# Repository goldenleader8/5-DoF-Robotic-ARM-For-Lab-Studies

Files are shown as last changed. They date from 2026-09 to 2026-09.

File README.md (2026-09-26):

# 5-DoF Robotic ARM For Lab Studies

Purwarupa lengan robot 5-Derajat Kebebasan (5-DoF) yang dikembangkan oleh **Kelompok Studi Robotika (KSR)**, Fakultas Teknologi Industri, Universitas Atma Jaya Yogyakarta (UAJY), sebagai instrumen pembelajaran dan praktikum untuk mata kuliah **Otomasi Industri dan Robotika**.

Proyek ini menjembatani teori kinematika ruang tiga dimensi dengan penerapan nyata pada perangkat keras fisik, melalui tiga tahap utama: **pemodelan**, **pembuatan purwarupa**, dan **pengujian pergerakan sendi**.

## Fitur Utama

- **Forward Kinematics (FK)** — melacak posisi koordinat ujung lengan (end-effector) secara presisi berdasarkan input sudut sendi, menggunakan parameter Denavit-Hartenberg (DH) hybrid yang diekstraksi langsung dari desain URDF.
- **Inverse Kinematics (IK)** — diselesaikan dengan algoritma analitik-numerik **Damped Least Squares (DLS)** untuk menstabilkan pergerakan di area singularitas mekanis, tanpa memerlukan pelatihan AI.
- **Simulasi Virtual (MATLAB)** — lingkungan simulasi berbasis URDF sebagai lapisan perlindungan sebelum program dieksekusi ke mesin fisik, termasuk simulasi Monte Carlo (30.000 kombinasi sudut sendi acak) untuk memetakan titik rawan tabrakan.
- **Interlock Keamanan** — sistem kendali Python memblokir eksekusi trajektori yang berpotensi menabrak bidang kerja (meja).

## Struktur Perangkat Keras

- Base link, tiga tautan ekstensi menengah, dan end-effector — dicetak 3D menggunakan filamen PETG pada printer Creality Ender 3 V3 Plus.
- Desain komponen dibuat menggunakan Autodesk Fusion.
- Lima motor servo **Dynamixel AX-12A** yang dirangkai seri, menyediakan engsel putar independen untuk base, bahu, siku, dan pergelangan tangan ganda.
- Kendali menggunakan mikrokontroler dengan komunikasi serial pada 57600 bps.

## Struktur Repositori

```
├── 5DofARM.py              # Skrip kendali utama (FK, IK/DLS, komunikasi serial ke Dynamixel)
├── Simulasi_URDF_GUI.m     # GUI simulasi lengan robot berbasis URDF di MATLAB
├── Test_Collision.m        # Simulasi Monte Carlo untuk deteksi area rawan tabrakan
├── LICENSE
└── README.md
```

## Dasar Matematika

### Forward Kinematics — Transformasi Homogen Denavit-Hartenberg

Setiap frame *i* dihubungkan ke frame sebelumnya melalui matriks transformasi homogen 4x4:

```
        [ cosθᵢ   -sinθᵢ·cosαᵢ    sinθᵢ·sinαᵢ    aᵢ·cosθᵢ ]
Tᵢ  =   [ sinθᵢ    cosθᵢ·cosαᵢ   -cosθᵢ·sinαᵢ    aᵢ·sinθᵢ ]
        [   0         sinαᵢ          cosαᵢ          dᵢ    ]
        [   0            0              0            1    ]
```

Keterangan:
- `Tᵢ` : matriks transformasi homogen
- `θᵢ` : sudut sendi (joint angle)
- `αᵢ` : pilin link (link twist)
- `aᵢ` : panjang link (link length)
- `dᵢ` : offset link (link offset)

Posisi akhir end-effector diperoleh dari perkalian berurutan seluruh matriks transformasi frame (8 frame, kombinasi sendi dinamis dan frame statis hasil ekstraksi geometri fisik robot).

**Parameter DH robot ini:**

| Frame (i) | aᵢ (m) | αᵢ (°) | dᵢ (m) | θᵢ (°) | Keterangan |
|---|---|---|---|---|---|
| 1 | 0.0 | 0.0 | 0.021 | θ₁* | Base joint dinamis (Yaw) |
| 2 | 0.0075 | -90.0 | 0.006448 | 90.0 | Transisi orientasi sumbu bahu |
| 3 | 0.036878 | 0.0 | 0.0215 | θ₂* | Shoulder joint dinamis (Pitch) |
| 4 | 0.120266 | 0.0 | -0.0051 | 16.3429 | Geometri statis Link 1 |
| 5 | 0.036878 | 0.0 | 0.005 | θ₃* | Elbow joint dinamis (Pitch) |
| 6 | 0.008 | 90.0 | 0.015 | 102.529 | Geometri statis Link 2 |
| 7 | 0.036878 | 0.0 | 0.0735 | θ₄* | Wrist joint dinamis (Pitch) |
| 8 | 0.008 | 90.0 | 0.0465 | 102.529 | Jarak absolut ke End-Effector |

\* `θₓ*` merepresentasikan variabel sudut dinamis dari aktuator, yang berubah real-time sesuai hasil perhitungan inverse kinematics.

### Inverse Kinematics — Damped Least Squares (DLS)

Untuk menghindari ketidakstabilan pada titik singularitas mekanis (kelemahan metode pseudo-invers konvensional), perubahan sudut sendi per iterasi dihitung dengan menambahkan faktor redaman:

```
Δθₖ = Jᵀ (J·Jᵀ + λ²·I)⁻¹ · eₖ
```

Keterangan:
- `Δθₖ` : vektor perubahan sudut sendi
- `J` : matriks Jacobian numerik (dihitung dengan diferensiasi maju berhingga)
- `Jᵀ` : transpos matriks Jacobian
- `λ` : skalar redaman (damping factor)
- `I` : matriks identitas
- `eₖ` : vektor error spasial (spatial error)

Iterasi berlangsung hingga vektor error spasial konvergen menuju target koordinat, tanpa mekanisme *joint limit clamping* (dinonaktifkan untuk menghindari minima lokal).

## Hasil Eksperimen (Ringkasan)

| Aspek | Hasil |
|---|---|
| Deviasi rata-rata Forward Kinematics | 0,0555 m (X: 0,0315 m, Y: 0,0358 m, Z: 0,0153 m) |
| Error residual Inverse Kinematics (DLS) | 1–4 mm (0,25%–1,02% dari radius jangkauan) |
| Batas keamanan vertikal bawah | 0,025 m |

## Persyaratan

- Python 3.x dengan pustaka `dynamixel_sdk`
- MATLAB (untuk simulasi URDF dan uji tabrakan)
- Port serial (COM) untuk komunikasi dengan motor Dynamixel AX-12A

## Cara Menjalankan

1. Hubungkan motor Dynamixel AX-12A ke port serial (default: `COM6`, baudrate `57600`).
2. Jalankan `5DofARM.py` untuk mengendalikan lengan robot secara langsung.
3. Gunakan `Simulasi_URDF_GUI.m` di MATLAB untuk menjalankan simulasi virtual sebelum eksekusi ke perangkat fisik.
4. Gunakan `Test_Collision.m` untuk menjalankan simulasi Monte Carlo dan memvalidasi batas ruang kerja aman.

## Kontributor

Kelompok Studi Robotika (KSR), Fakultas Teknologi Industri, Universitas Atma Jaya Yogyakarta.

- **Desain & perakitan hardware (lengan robot, 3D printing, wiring)**: [Dionisio Raditya](https://github.com/dionisioraditya) 
- **Software (FK/IK, kontrol Python, simulasi MATLAB/URDF)**: Jonathan.

## Lisensi

Proyek ini dilisensikan di bawah [MIT License](LICENSE).

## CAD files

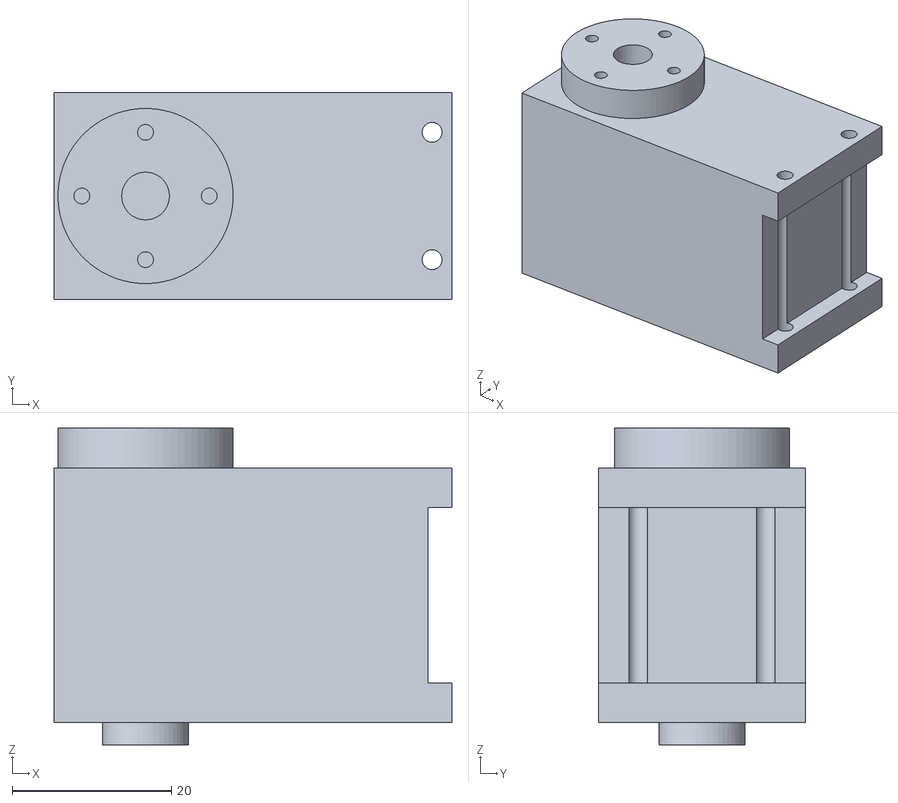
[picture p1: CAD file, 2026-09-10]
meshes/AX_12A_remake-v1-2.stl
50.0 x 26.0 x 39.8

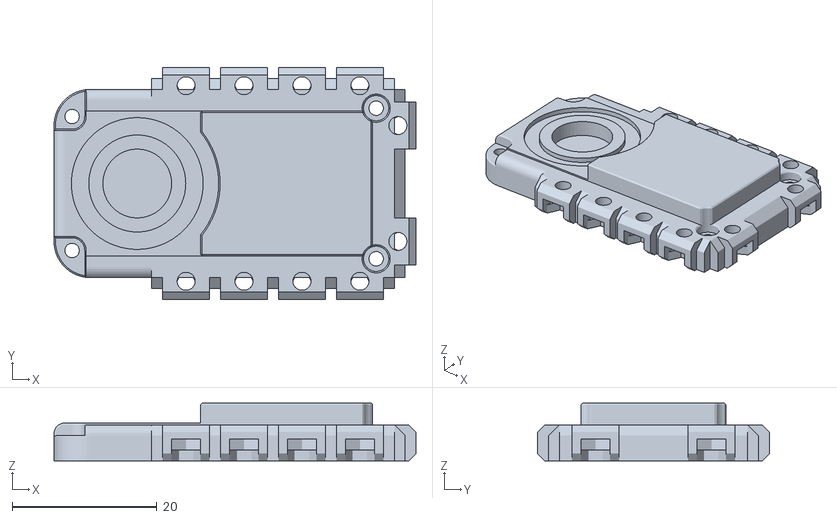
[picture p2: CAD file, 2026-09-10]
meshes/holder-v2_AX-12A-v1-7_AX-12A-02-7.stl
50.0 x 32.0 x 8.00

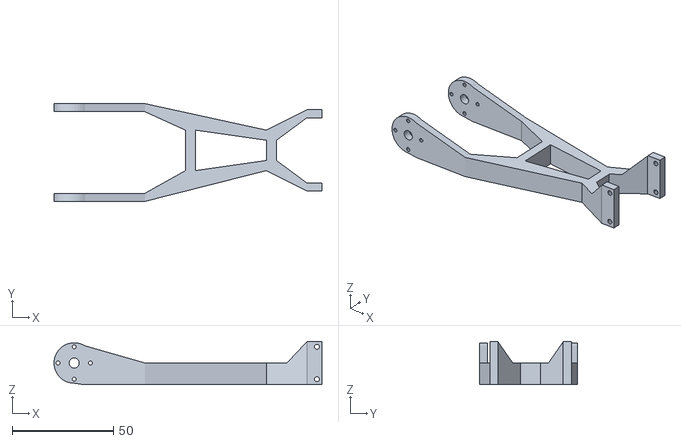
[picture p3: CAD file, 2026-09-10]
meshes/link_1_v2-v6.stl
132.5 x 48.3 x 21.5

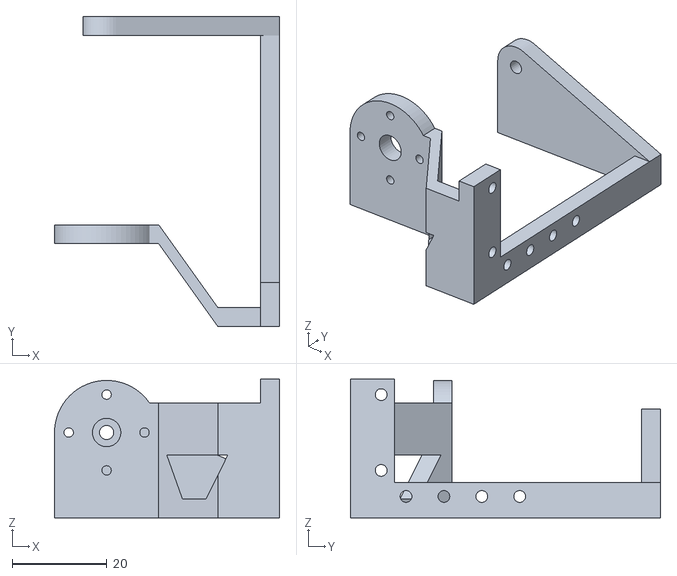
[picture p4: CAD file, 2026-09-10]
meshes/link_2_V2-v5.stl
47.5 x 65.5 x 29.2

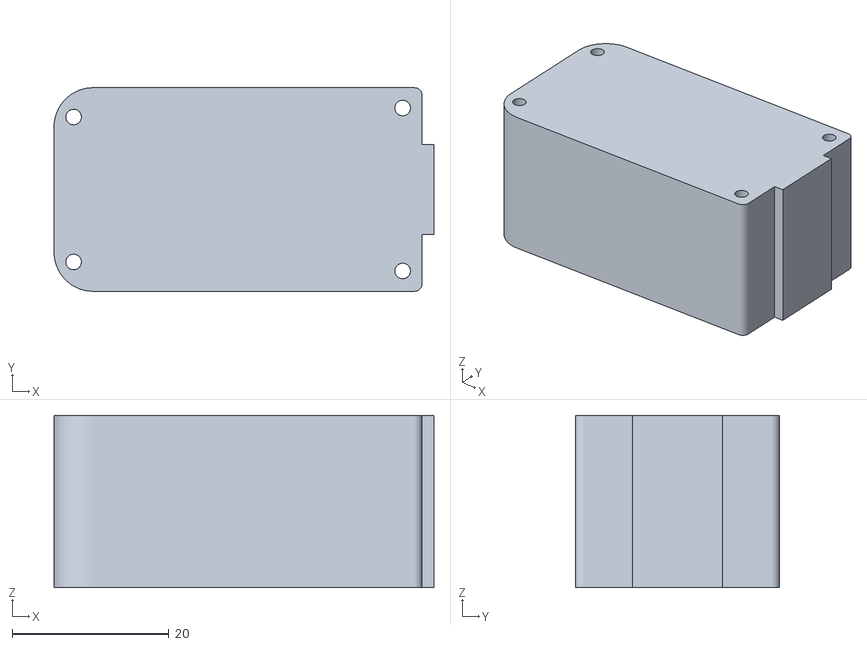
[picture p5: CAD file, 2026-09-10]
meshes/holder-v2_AX-12A-v1-7_AX-12A-01-7.stl
48.5 x 26.0 x 22.0

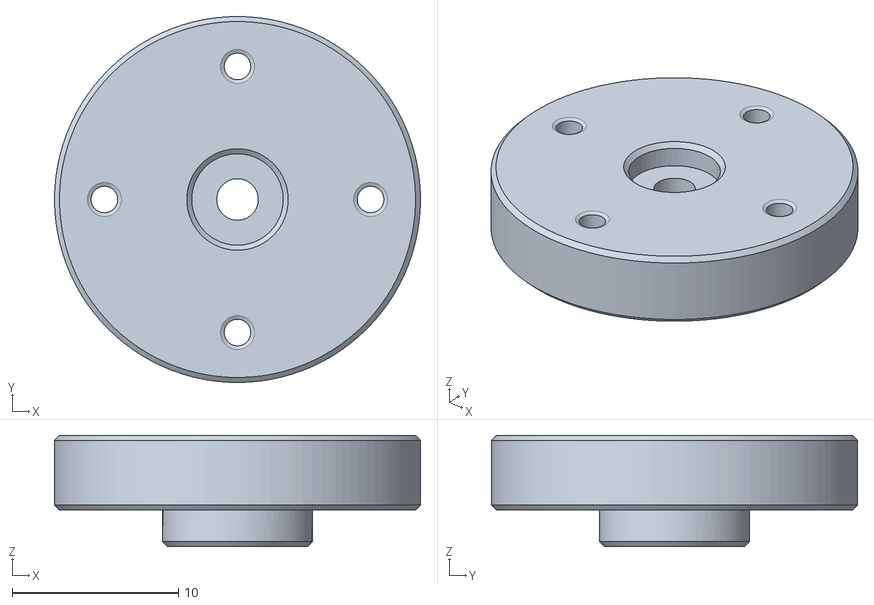
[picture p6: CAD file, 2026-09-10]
meshes/holder-v2_AX-12A-v1-7_AX-12A-04-7.stl
22.0 x 22.0 x 6.70

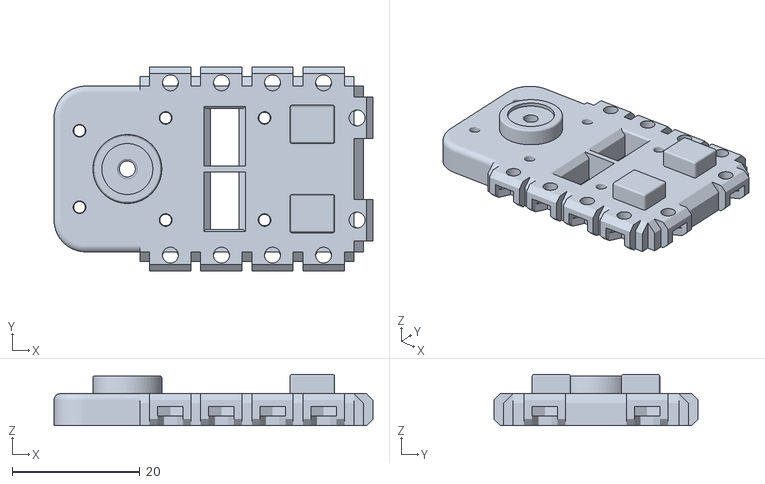
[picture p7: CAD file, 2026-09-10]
meshes/holder-v2_AX-12A-v1-7_AX-12A-03-7.stl
50.0 x 32.0 x 8.00

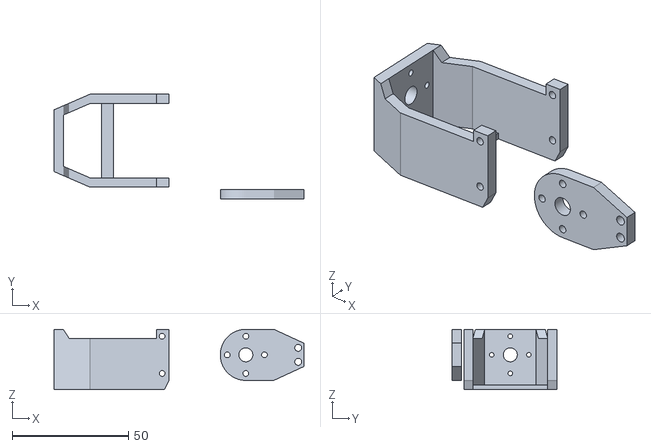
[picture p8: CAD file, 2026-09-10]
meshes/end_effector-v5.stl
107.5 x 45.0 x 26.0

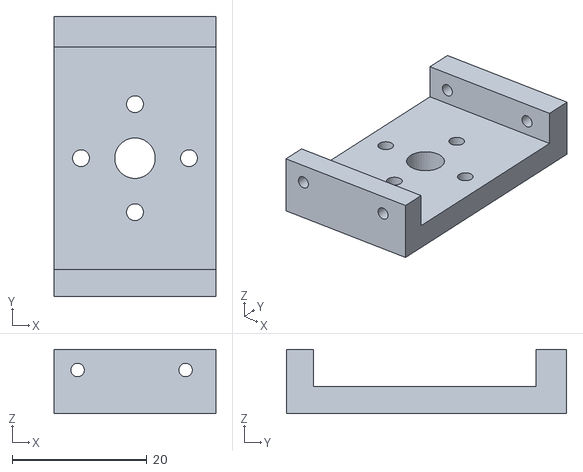
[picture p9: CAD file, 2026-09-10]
meshes/base_link-v7.stl
24.0 x 41.5 x 9.50

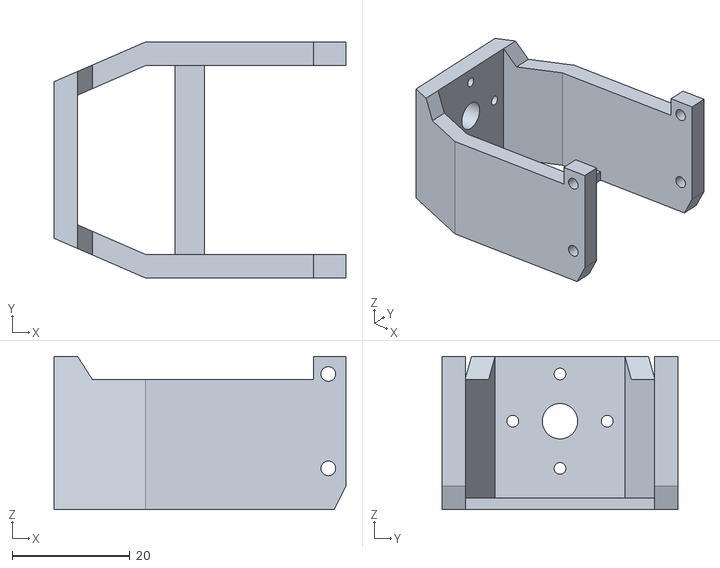
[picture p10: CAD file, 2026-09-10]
meshes/link_3-v10.stl
49.5 x 40.0 x 26.0

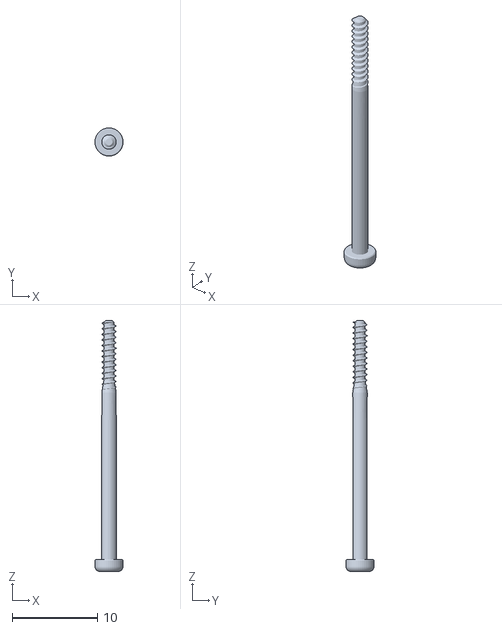
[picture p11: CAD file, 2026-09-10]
meshes/holder-v2_AX-12A-v1-7_SetScrew-7.stl
3.30 x 3.29 x 29.4

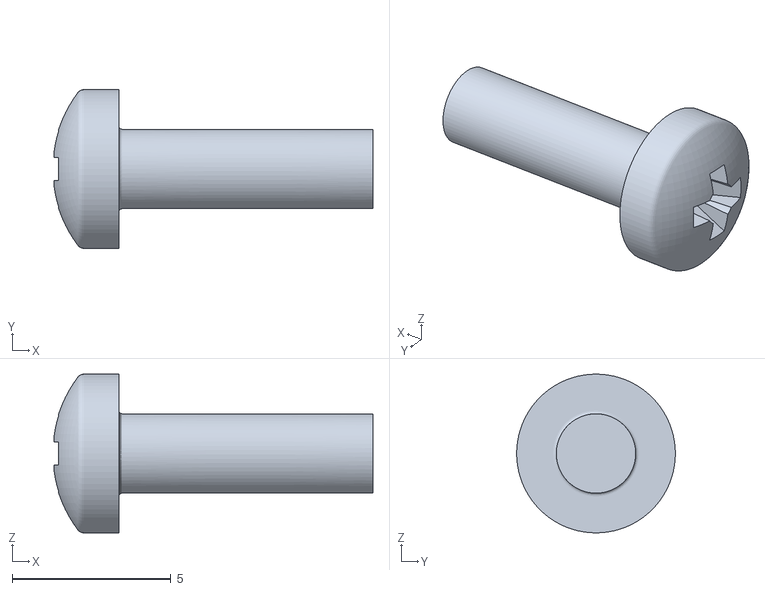
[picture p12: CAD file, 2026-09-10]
meshes/holder-v2_AX-12A-v1-7_pan-head-cross-recess-screw_iso_ISO-7045---M2.5-x-8---Z-----8C-7.stl
10.0 x 5.00 x 5.00

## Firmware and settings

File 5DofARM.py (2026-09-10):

import os
import sys
import math
import time
import numpy as np
import random
from dynamixel_sdk import * 

COM_PORT = 'COM6'
BAUDRATE = 57600
PROTOCOL_VERSION = 2.0

ADDR_TORQUE_ENABLE = 64
ADDR_GOAL_POSITION = 116
ADDR_PRESENT_POSITION = 132
ADDR_PROFILE_ACCELERATION = 108
ADDR_PROFILE_VELOCITY = 112

DXL_RAW_MAX = 4095      
DXL_DEG_RANGE = 360.0   

ID_BASE    = 1
ID_BAHU    = 2
ID_SIKU2   = 18   
ID_WRIST   = 3    
ID_POINTER = 15   

MID_ID1  = 180.00    # Titik Home Fisik Base 
MID_ID2  = 100.00    # Titik Home Fisik Bahu
MID_ID3  = 358.00    # Titik Home Fisik Wrist
MID_ID15 = 0.5       # Titik Home Pointer
MID_ID18 = 1.50      # Titik Home Fisik Siku2

MID_MAP = {
    ID_BASE: 0.0,
    ID_BAHU: 0.0,
    ID_SIKU2: 0.0,
    ID_WRIST: 0.0,
    ID_POINTER: 0.0,
}

SERVO_LIMITS = {
    ID_BASE:    (0.09, 359.91),
    ID_BAHU:    (30.00, 200.00),
    ID_SIKU2:   (1.14, 185.00),
    ID_WRIST:   (0.70, 358.59),
    ID_POINTER: (0.09, 143.96),
}

#DH Parameters
d1, theta_off1, a1, alpha1_deg = 0.021, 0.0 - MID_ID1, 0.0, 0.0
d2, theta2_deg, a2, alpha2_deg = 0.006448, 90.0, 0.0075, -90.0
d3, theta_off3, a3, alpha3_deg = 0.0215, -102.529 + MID_ID2, 0.036878, 0.0
d4, theta4_deg, a4, alpha4_deg = -0.0051, 16.3429, 0.120266, 0.0
d5, theta_off5, a5, alpha5_deg = 0.005, -16.3429 - MID_ID18, 0.036878, 0.0
d6, theta6_deg, a6, alpha6_deg = 0.015, 102.529, 0.008, 90.0
d7, theta_off7, a7, alpha7_deg = 0.0735, -102.529 - MID_ID3, 0.036878, 0.0
d8, theta8_deg, a8, alpha8_deg = 0.0465, 102.529, 0.008, 90.0

alpha1 = alpha1_deg * math.pi / 180.0
alpha2 = alpha2_deg * math.pi / 180.0
alpha3 = alpha3_deg * math.pi / 180.0
alpha4 = alpha4_deg * math.pi / 180.0
alpha5 = alpha5_deg * math.pi / 180.0
alpha6 = alpha6_deg * math.pi / 180.0
alpha7 = alpha7_deg * math.pi / 180.0
alpha8 = alpha8_deg * math.pi / 180.0

theta2 = theta2_deg * math.pi / 180.0
theta4 = theta4_deg * math.pi / 180.0
theta6 = theta6_deg * math.pi / 180.0
theta8 = theta8_deg * math.pi / 180.0

def mat4x4():
    return [
    [0.0, 0.0, 0.0, 0.0],
    [0.0, 0.0, 0.0, 0.0],
    [0.0, 0.0, 0.0, 0.0],
    [0.0, 0.0, 0.0, 0.0]
]
    
def dh_matrix(theta, alpha, d, a):
    return [
    [math.cos(theta), (-1) * math.sin(theta) * math.cos(alpha), math.sin(theta) * math.sin(alpha), a * math.cos(theta)],
    [math.sin(theta), math.cos(theta) * math.cos(alpha), (-1) * math.cos(theta) * math.sin(alpha), a * math.sin(theta)],
    [0, math.sin(alpha), math.cos(alpha), d],
    [0, 0, 0, 1]
]

portHandler = PortHandler(COM_PORT)
packetHandler = PacketHandler(PROTOCOL_VERSION)

def kalibrasi_awal():
    home1, home2, home3, home4 = MID_ID1, MID_ID2, MID_ID18, MID_ID3
    
    if not cek_tabrakan_meja(home1, home2, home3, home4):
        print("! Kalibrasi awal DIBATALKAN: posisi HOME akan menabrak meja !")
        return
    
    jawab = input("Gerakkan lengan ke posisi HOME sekarang untuk kalibrasi awal? (y/n): ").strip().lower()
    
    if jawab != 'y':
        print("Kalibrasi awal dilewati. Lengan tetap di posisi terakhir (torque tetap aktif/menahan).")
        return
    
    x, y, z, T_total = forwardkin(home1, home2, home3, home4)
    send_all(home1, home2, home3, home4)

    sudut_POINTER = MID_ID15
    senddata(ID_POINTER, sudut_POINTER)
    
    print("Kalibrasi awal selesai -> lengan di posisi HOME (pointer diatur ke atas).")

def init():
    ids = [ID_BASE, ID_BAHU, ID_SIKU2, ID_WRIST, ID_POINTER]
    for dxl_id in ids:
        packetHandler.write4ByteTxRx(portHandler, dxl_id, ADDR_PROFILE_ACCELERATION, 20)
        packetHandler.write4ByteTxRx(portHandler, dxl_id, ADDR_PROFILE_VELOCITY, 40)
        
        result, error = packetHandler.write1ByteTxRx(portHandler, dxl_id, ADDR_TORQUE_ENABLE, 1)
        if result != COMM_SUCCESS:
            print(f"[ID {dxl_id}] GAGAL komunikasi: {packetHandler.getTxRxResult(result)}")
        elif error != 0:
            print(f"[ID {dxl_id}] Servo error: {packetHandler.getRxPacketError(error)}")
        else:
            print(f"[ID {dxl_id}] Torque enabled OK")
    
    kalibrasi_awal()

def identity(mat):
    for i in range(4):
      for j in range(4):
        mat[i][j] = 1.0 if i == j else 0.0
    return mat

matA = mat4x4()
matB = mat4x4()
matC = mat4x4()

def multiply(matA, matB, matC):
    for i in range(4):
      for j in range(4):
        matC[i][j] = 0
        for k in range(4):
          matC[i][j] += matA[i][k] * matB[k][j]

def forwardkin(theta1_deg, theta2_deg_in, theta3_deg, theta4_deg):
    tetha1 = (theta_off1 + theta1_deg) * math.pi / 180.0
    tetha3 = (theta_off3 - theta2_deg_in) * math.pi / 180.0 
    tetha5 = (theta_off5 + theta3_deg) * math.pi / 180.0
    tetha7 = (theta_off7 + theta4_deg) * math.pi / 180.0

    matT1 = dh_matrix(tetha1, alpha1, d1, a1)   # revolute
    matT2 = dh_matrix(theta2, alpha2, d2, a2)   # fixed
    matT3 = dh_matrix(tetha3, alpha3, d3, a3)   # revolute
    matT4 = dh_matrix(theta4, alpha4, d4, a4)  # fixed
    matT5 = dh_matrix(tetha5, alpha5, d5, a5)   # revolute
    matT6 = dh_matrix(theta6, alpha6, d6, a6)   # fixed
    matT7 = dh_matrix(tetha7, alpha7, d7, a7)   # revolute
    
    matT_tcp = [
        [0.9761863, -0.2169337, 0.0000000, -0.0204999],
        [0.2169337, 0.9761863, -0.0000000, -0.0045549],
        [-0.0000000, -0.0000000, 1.0000000, 0.1075027],
        [0.0, 0.0, 0.0, 1.0]
    ]

    T_total = mat4x4()
    temp = mat4x4()

    identity(T_total)
    multiply(T_total, matT1, temp)
    multiply(temp, matT2, T_total)
    multiply(T_total, matT3, temp)
    multiply(temp, matT4, T_total)
    multiply(T_total, matT5, temp)
    multiply(temp, matT6, T_total)
    multiply(T_total, matT7, temp)
    multiply(temp, matT_tcp, T_total)

    x = T_total[0][3]
    y = T_total[1][3]
    z = T_total[2][3]

    return x, y, z, T_total

Z_FLOOR = 0.025  

def position_all_z(theta1_deg, theta2_deg_in, theta3_deg, theta4_deg): 
    tetha1 = (theta_off1 + theta1_deg) * math.pi / 180.0
    tetha3 = (theta_off3 - theta2_deg_in) * math.pi / 180.0  
    tetha5 = (theta_off5 + theta3_deg) * math.pi / 180.0
    tetha7 = (theta_off7 + theta4_deg) * math.pi / 180.0

    matT1 = dh_matrix(tetha1, alpha1, d1, a1)
    matT2 = dh_matrix(theta2, alpha2, d2, a2)
    matT3 = dh_matrix(tetha3, alpha3, d3, a3)
    matT4 = dh_matrix(theta4, alpha4, d4, a4)
    matT5 = dh_matrix(tetha5, alpha5, d5, a5)
    matT6 = dh_matrix(theta6, alpha6, d6, a6)
    matT7 = dh_matrix(tetha7, alpha7, d7, a7)
    matT_tcp = [
        [0.9761863, -0.2169337, 0.0000000, -0.0204999],
        [0.2169337, 0.9761863, -0.0000000, -0.0045549],
        [-0.0000000, -0.0000000, 1.0000000, 0.1075027],
        [0.0, 0.0, 0.0, 1.0]
    ]

    T_total = mat4x4()
    temp = mat4x4()
    identity(T_total)

    z_checkpoints = []

    multiply(T_total, matT1, temp)
    multiply(temp, matT2, T_total)

    multiply(T_total, matT3, temp)      # setelah bahu
    z_checkpoints.append(temp[2][3])
    multiply(temp, matT4, T_total)

    multiply(T_total, matT5, temp)      # setelah siku2
    z_checkpoints.append(temp[2][3])
    multiply(temp, matT6, T_total)

    multiply(T_total, matT7, temp)      # setelah wrist
    z_checkpoints.append(temp[2][3])

    multiply(temp, matT_tcp, T_total)   # ujung capit TCP
    z_checkpoints.append(T_total[2][3])

    x = T_total[0][3]
    y = T_total[1][3]
    z_tip = T_total[2][3]

    return x, y, z_tip, z_checkpoints

def cek_tabrakan_meja(theta1_deg, theta2_deg, theta3_deg, theta4_deg): #Return True kalau aman, False kalau berpotensi nabrak
    x, y, z_ee, z_checkpoints = position_all_z(theta1_deg, theta2_deg, theta3_deg, theta4_deg)
    return all(z >= Z_FLOOR for z in z_checkpoints)

def get_jacobian(theta1, theta2, theta3, theta4): #turunan numerik (finite difference)
    delta = 0.01 
    J = [
        [0.0, 0.0, 0.0, 0.0], 
        [0.0, 0.0, 0.0, 0.0], 
        [0.0, 0.0, 0.0, 0.0], 
    ]
    
    thetas_original = [theta1, theta2, theta3, theta4]
    x0, y0, z0, _ = forwardkin(*thetas_original)
    
    for j in range(4):
        thetas_new = thetas_original.copy()
        thetas_new[j] += delta
        x1, y1, z1, _ = forwardkin(*thetas_new)
        J[0][j] = (x1 - x0) / delta
        J[1][j] = (y1 - y0) / delta
        J[2][j] = (z1 - z0) / delta
    return J

def inverse_3x3(M):
    a, b, c = M[0]
    d, e, f = M[1]
    g, h, i = M[2]
    
    det = a * (e * i - f * h) - b * (d * i - f * g) + c * (d * h - e * g)
    
    if abs(det) < 1e-9:
        det = 1e-9 if det >= 0 else -1e-9
    
    inv = [
        [(e * i - f * h) / det, (c * h - b * i) / det, (b * f - c * e) / det],
        [(f * g - d * i) / det, (a * i - c * g) / det, (c * d - a * f) / det],
        [(d * h - e * g) / det, (b * g - a * h) / det, (a * e - b * d) / det]
    ]
    
    return inv

def matmul_3x3_3x1(M, v):
    return [
        M[0][0] * v[0] + M[0][1] * v[1] + M[0][2] * v[2],
        M[1][0] * v[0] + M[1][1] * v[1] + M[1][2] * v[2],
        M[2][0] * v[0] + M[2][1] * v[1] + M[2][2] * v[2],
    ]

def transpose_3x4(mat):
    T = [[0.0] * 3 for _ in range(4)]
    for i in range(3):
        for j in range(4):
            T[j][i] = mat[i][j]
    return T

def inversekin(x_target, y_target, z_target, thetas_original): #Damped Least Squares (pseudo-invers Jacobian yang diminimalkan norma-2 kecepatan sendi sambil mengikuti target, dengan tambahan redaman λ dekat singularitas)
    max_iteration = 10000
    
    ids_urut = [ID_BASE, ID_BAHU, ID_SIKU2, ID_WRIST]
    
    home_seed = [
        MID_ID1 - MID_MAP[ID_BASE],
        MID_ID2 - MID_MAP[ID_BAHU],
        MID_ID18 - MID_MAP[ID_SIKU2],
        MID_ID3 - MID_MAP[ID_WRIST]
    ]
    
    seeds_to_try = [
        list(thetas_original),
        home_seed,
        [
            random.uniform(SERVO_LIMITS[ID_BASE][0], SERVO_LIMITS[ID_BASE][1]) - MID_MAP[ID_BASE],
            random.uniform(SERVO_LIMITS[ID_BAHU][0], SERVO_LIMITS[ID_BAHU][1]) - MID_MAP[ID_BAHU],
            random.uniform(SERVO_LIMITS[ID_SIKU2][0], SERVO_LIMITS[ID_SIKU2][1]) - MID_MAP[ID_SIKU2],
            random.uniform(SERVO_LIMITS[ID_WRIST][0], SERVO_LIMITS[ID_WRIST][1]) - MID_MAP[ID_WRIST]
        ]
    ]

    best_thetas = None
    best_error = float('inf')
    
    for seed_idx, current_seed in enumerate(seeds_to_try):
        thetas_list = list(current_seed)
        jaraktotal = float('inf')
        
        for iteration in range(max_iteration):
            x_now, y_now, z_now, _ = forwardkin(*thetas_list)
            err_x = x_target - x_now
            err_y = y_target - y_now
            err_z = z_target - z_now
            
            jaraktotal = math.sqrt((err_x * err_x) + (err_y * err_y) + (err_z * err_z))
            if jaraktotal < 0.001:
                break
            
            J = get_jacobian(*thetas_list)
            J_T = transpose_3x4(J)
            
            lam = 0.05
            JJt = [[sum(J[a][k] * J[b][k] for k in range(4)) for b in range(3)] for a in range(3)]
            for a in range(3):
                JJt[a][a] += lam * lam
            
            JJt_inv = inverse_3x3(JJt)
            temp_vec = matmul_3x3_3x1(JJt_inv, [err_x, err_y, err_z])    
            
            for i in range(4):
                delta_theta = (J_T[i][0] * temp_vec[0]) + (J_T[i][1] * temp_vec[1]) + (J_T[i][2] * temp_vec[2])
                thetas_list[i] += delta_theta
        
        if jaraktotal < 0.01:
            best_thetas = thetas_list
            best_error = jaraktotal
            print(f"IK sukses di Seed {seed_idx+1} dalam {iteration} iterasi. Error sisa: {jaraktotal:.5f} m")
            break
        
        if jaraktotal < best_error:
            best_error = jaraktotal
            best_thetas = list(thetas_list)
        
        if seed_idx < 2:
            print(f"! [IK Fallback] Seed {seed_idx+1} gagal konvergen (Error {jaraktotal:.5f}m). Mencoba rute alternatif...")
    
    if best_error >= 0.01:
        print(f"! IK GAGAL setelah 3 percobaan. Target mungkin di luar jangkauan. Error sisa: {best_error:.5f} m")
        print("  Servo TIDAK akan digerakkan ke solusi ini karena tidak akurat.")
        return best_thetas[0], best_thetas[1], best_thetas[2], best_thetas[3], False
    
    if not cek_tabrakan_meja(*best_thetas):
        print("! IK DITOLAK: solusi ditemukan, tapi akan membuat lengan menabrak meja!")
        print("  Servo TIDAK digerakkan. Coba target lain (misal naikkan nilai Z).")
        return best_thetas[0], best_thetas[1], best_thetas[2], best_thetas[3], False
    
    return best_thetas[0], best_thetas[1], best_thetas[2], best_thetas[3], True

def hitung_pointdegree(T_total):
    zx = T_total[0][2]
    zy = T_total[1][2]
    zz = T_total[2][2]

    horizontal = math.sqrt(zx*zx + zy*zy)
    pitch_dunia_deg = math.degrees(math.atan2(horizontal, zz))

    degree_pointer_theta = MID_ID15 - pitch_dunia_deg   # tanpa +90.0

    point_min_theta = SERVO_LIMITS[ID_POINTER][0] - MID_MAP[ID_POINTER]
    point_max_theta = SERVO_LIMITS[ID_POINTER][1] - MID_MAP[ID_POINTER]
    degree_pointer_theta = max(point_min_theta, min(point_max_theta, degree_pointer_theta))
    return degree_pointer_theta
    
def cekbatas(dxl_id, theta_deg):
    sudut_fisik = MID_MAP[dxl_id] + theta_deg
    min_lim, max_lim = SERVO_LIMITS[dxl_id]
    aman = (min_lim <= sudut_fisik <= max_lim)
    return aman, sudut_fisik, min_lim, max_lim

def inputvalidation(prompt, dxl_id):
    while True:
        nilai_str = input(prompt)
        try:
            theta_deg = float(nilai_str)
        except ValueError:
            print("Input harus berupa angka (boleh desimal, misal 12.5)! Coba lagi.")
            continue
        
        aman, sudut_fisik, min_lim, max_lim = cekbatas(dxl_id, theta_deg)
        if not aman:
            theta_min_valid = min_lim - MID_MAP[dxl_id]
            theta_max_valid = max_lim - MID_MAP[dxl_id]
            print(f"! Di luar jangkauan servo! Sudut fisik hasil ({sudut_fisik:.2f}°) "
                  f"harus antara {min_lim}° - {max_lim}°.")
            print(f"  Artinya theta yang valid: {theta_min_valid:.2f}° sampai {theta_max_valid:.2f}°. Coba lagi.")
            continue
        return theta_deg
    
def senddata(dxl_id, theta_deg):
    truedegree = MID_MAP[dxl_id] + theta_deg
    min_lim, max_lim = SERVO_LIMITS[dxl_id]
    sudut_fisik = max(min_lim, min(max_lim, truedegree))
    raw_position = degreetoraw(sudut_fisik)
    
    result, error = packetHandler.write4ByteTxRx(portHandler, dxl_id, ADDR_GOAL_POSITION, raw_position)
    if result != COMM_SUCCESS:
        print(f"[ID {dxl_id}] GAGAL kirim goal: {packetHandler.getTxRxResult(result)}")
    elif error != 0:
        print(f"[ID {dxl_id}] Servo error: {packetHandler.getRxPacketError(error)}")
    else:
        print(f"[ID {dxl_id}] Goal terkirim -> raw={raw_position} ({sudut_fisik:.2f}°)")

def send_all(theta1_deg, theta2_deg, theta3_deg, theta4_deg):
    senddata(ID_BASE, theta1_deg)
    senddata(ID_BAHU, theta2_deg)
    senddata(ID_SIKU2, theta3_deg)
    senddata(ID_WRIST, theta4_deg)
    
def rawtodegree(raw_value):
    return raw_value * (DXL_DEG_RANGE / DXL_RAW_MAX)

def degreetoraw(deg_value):
    return round(deg_value * (DXL_RAW_MAX / DXL_DEG_RANGE))

def read_theta(dxl_id):
    raw_pos, dxl_comm_result, dxl_error = packetHandler.read4ByteTxRx(portHandler, dxl_id, ADDR_PRESENT_POSITION)
    if dxl_comm_result != COMM_SUCCESS:
        print(f"[ID {dxl_id}] GAGAL baca posisi: {packetHandler.getTxRxResult(dxl_comm_result)}")
        raise RuntimeError(f"Gagal membaca posisi servo ID {dxl_id} (komunikasi error)")
    if dxl_error != 0:
        print(f"[ID {dxl_id}] Servo error saat baca posisi: {packetHandler.getRxPacketError(dxl_error)}")
        raise RuntimeError(f"Servo ID {dxl_id} melaporkan error saat dibaca")

    sudut_fisik = rawtodegree(raw_pos)
    theta = sudut_fisik - MID_MAP[dxl_id]
    return theta
    
def readall():
    theta1_deg = read_theta(ID_BASE)
    theta2_deg = read_theta(ID_BAHU)
    theta3_deg = read_theta(ID_SIKU2)
    theta4_deg = read_theta(ID_WRIST) 
    return theta1_deg, theta2_deg, theta3_deg, theta4_deg
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
